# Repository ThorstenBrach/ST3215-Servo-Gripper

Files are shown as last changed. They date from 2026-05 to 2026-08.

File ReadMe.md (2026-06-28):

# ST3215 Servo Gripper














## Sprache / Language

- Deutsch: [Zur deutschen Version](#de-start)
- English: [Jump to English version](#en-start)

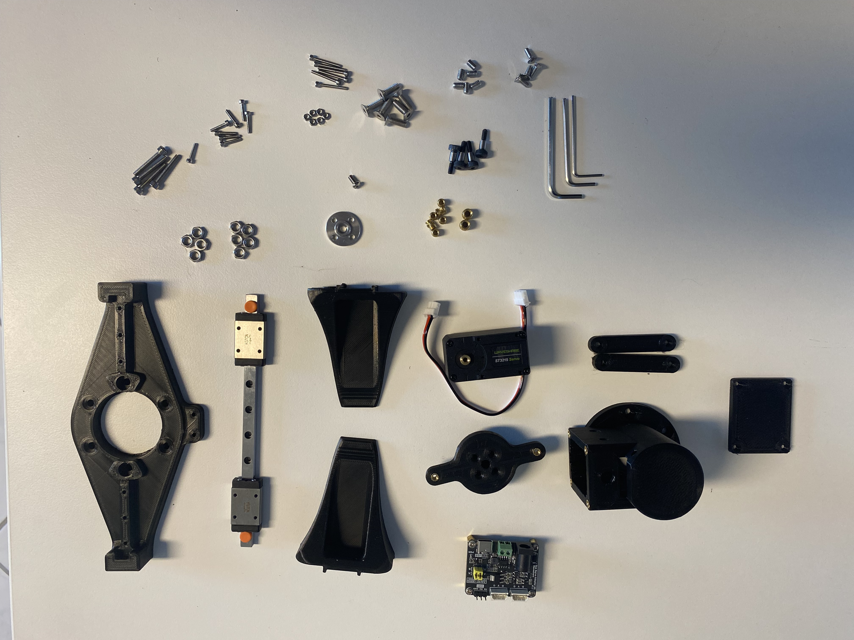
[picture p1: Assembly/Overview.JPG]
Servo Gripper Overview

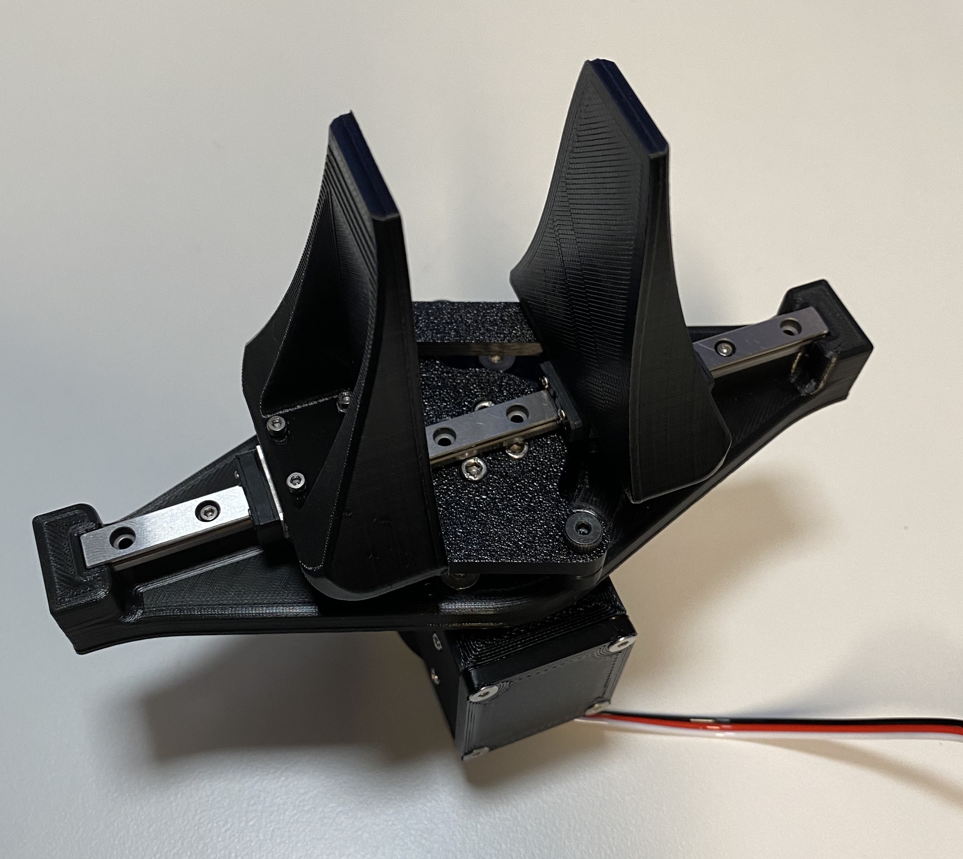
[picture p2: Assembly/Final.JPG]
Servo Gripper Final

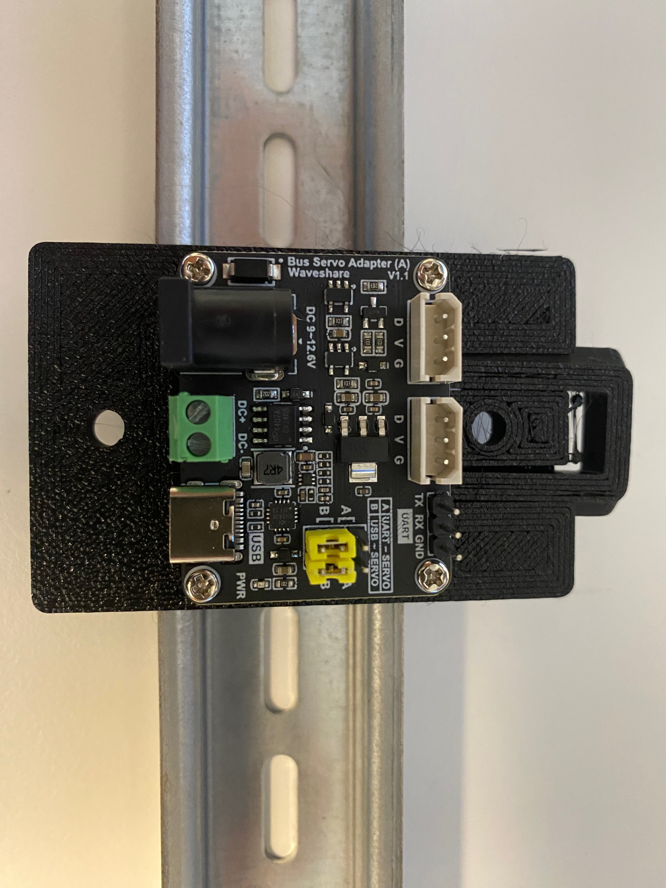
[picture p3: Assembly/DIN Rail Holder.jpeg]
DIN Rail Holder

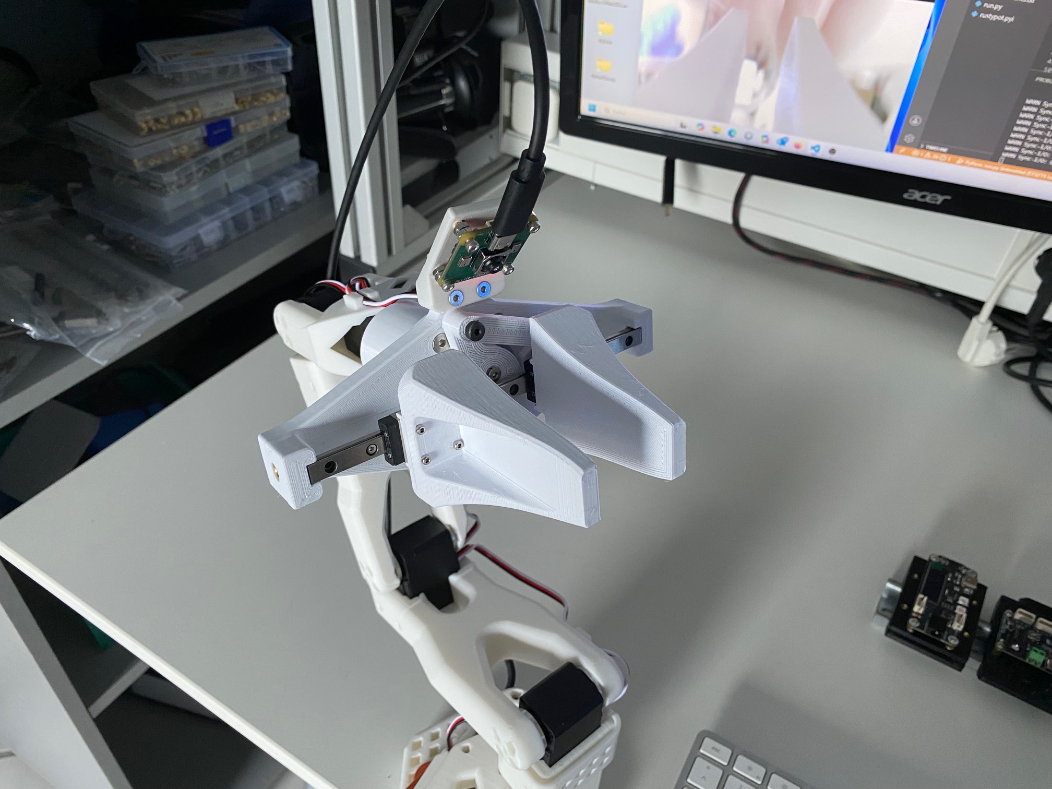
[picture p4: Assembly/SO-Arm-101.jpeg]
SO-ARM-101 Motorhousing


---

## Deutsch

[Zur Sprachauswahl](#language-selection)

Kompakter, kraftvoller ST3215 Servo Gripper zum Selberbauen mit 3D-Druckteilen, STEP-Modell, detaillierter Montageanleitung und kompletter Materialliste.

### Inhaltsverzeichnis

- [Projekt auf einen Blick](#de-ueberblick)
- [Demovideos](#de-videos)
- [Ordnerstruktur](#de-ordner)
- [Materialliste](#de-bom)
- [3D-Dateien (STL)](#de-stl)
- [CAD-Datei (STEP)](#de-step)
- [Montageanleitung](#de-assembly)
- [Software](#de-software)
- [Druck- und Setup-Hinweise](#de-hinweise)
- [Roadmap](#de-roadmap)
- [Mitwirken](#de-contrib)
- [Changelog](#de-changelog)
- [Lizenz](#de-license)

### Projekt auf einen Blick

| Thema | Details |
|---|---|
| Projekttyp | ST3215 Servo Gripper |
| Mechanik | 3D-gedruckte Baugruppen + Linearfuehrung MGN7H |
| Aktorik | Waveshare ST3215 Serial Bus Servo |
| CAD | STEP-Modell verfuegbar |
| Fertigung | STL-Dateien im Repository |
| Montage | Bebilderte Anleitung mit 25 Schritten |

### Demovideos

- Gesamtansicht: [Overview.mp4](./Video/Overview.mp4)
- Krafttest: [Force.mp4](./Video/Force.mp4)
- Anwendung mit Flasche: [Beer Bottle.mp4](./Video/Beer%20Bottle.mp4)

ST3215 Servo Gripper Overview GIF
ST3215 Servo Gripper Force Test GIF
ST3215 Servo Gripper Beer Bottle GIF

### Ordnerstruktur

| Ordner | Inhalt |
|---|---|
| [Assembly](./Assembly/) | Schritt-fuer-Schritt-Montage inkl. Bilder |
| [Material](./Material/) | Materialliste mit Mengen, Kosten und Links |
| [Software](./Software/) | Steuerungs-Software (in Entwicklung) |
| [Step](./Step/) | CAD-Datei im STEP-Format |
| [STL](./STL/) | Druckdateien fuer alle Bauteile |
| [Video](./Video/) | Demo- und Funktionstest-Videos |

### Materialliste

- [Material/Readme.md](./Material/Readme.md)

### 3D-Dateien (STL)

- [Baseplate.stl](./STL/Baseplate.stl)
- [Cam Holder.stl](./STL/Cam%20Holder.stl)
- [DIN Rail Holder Serial Board.stl](./STL/DIN%20Rail%20Holder%20Serial%20Board.stl)
- [DIN Rail Holder ESP32 Adapter.stl](./STL/DIN%20Rail%20Holder%20ESP32%20Adapter.stl)
- [Finger_1.stl](./STL/Finger_1.stl)
- [Finger_2.stl](./STL/Finger_2.stl)
- [Motorhousing.stl](./STL/Motorhousing.stl)
- [Motorhousing Cover.stl](./STL/Motorhousing%20Cover.stl)
- [Motorhousing Cover with Handle.stl](./STL/Motorhousing%20Cover%20with%20Handle.stl)
- [Motorhousing SO-ARM-101.stl](./STL/Motorhousing%20SO-ARM-101.stl)
- [Schwing Arm 1.stl](./STL/Schwing%20Arm%201.stl)
- [Schwing Arm 2.stl](./STL/Schwing%20Arm%202.stl)
- [Turnhead.stl](./STL/Turnhead.stl)

### CAD-Datei (STEP)

- [DIN Rail Holder Serial Board.step](./Step/DIN%20Rail%20Holder%20Serial%20Board.step)
- [Gripper.step](./Step/Gripper.step)

### Montageanleitung

- [Assembly/Readme.md](./Assembly/Readme.md)

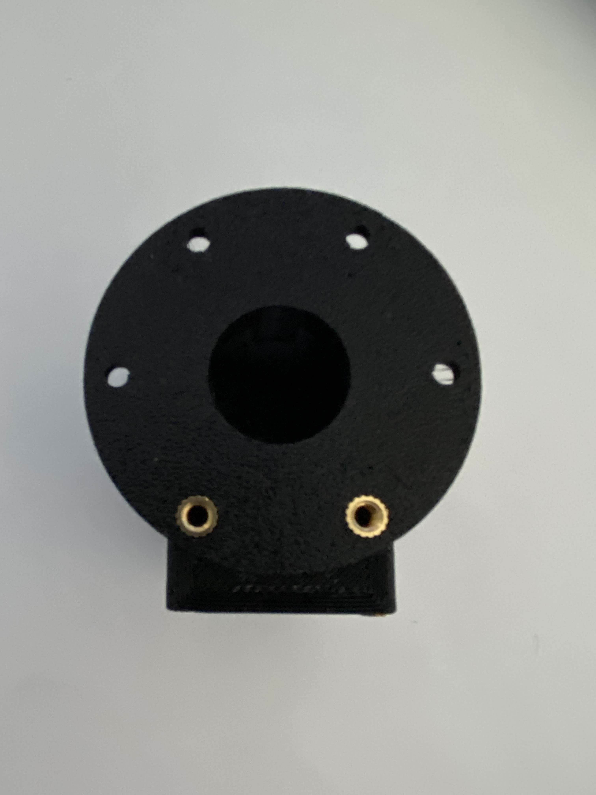
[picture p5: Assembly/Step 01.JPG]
Assembly Step 01

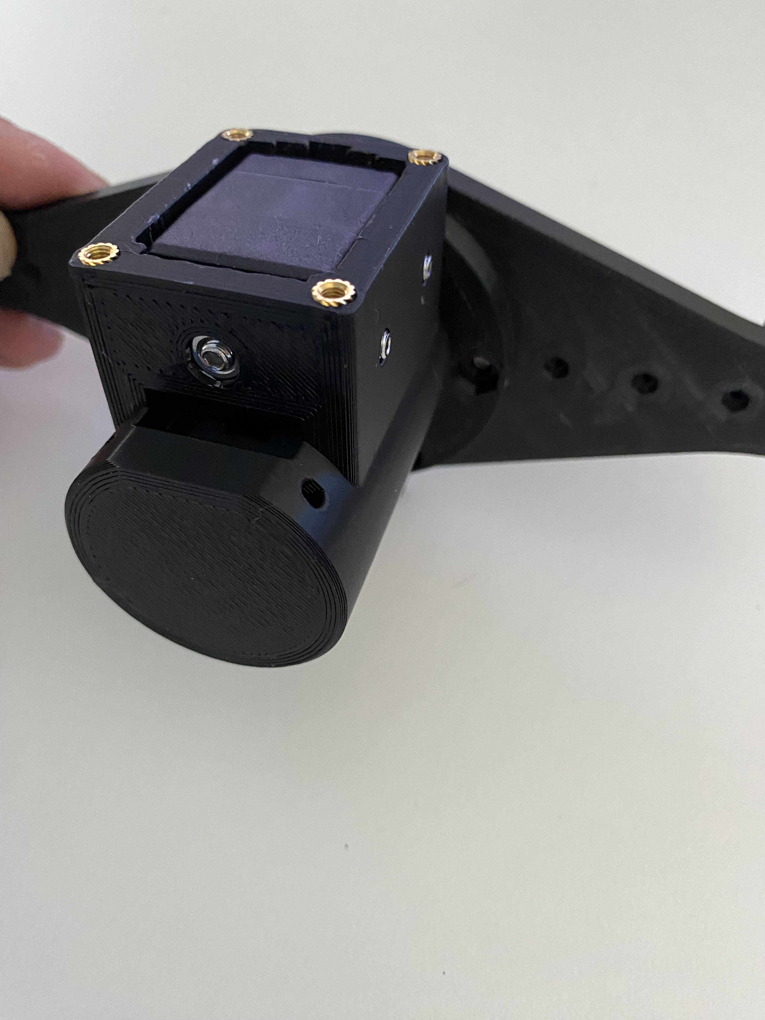
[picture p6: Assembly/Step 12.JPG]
Assembly Step 12

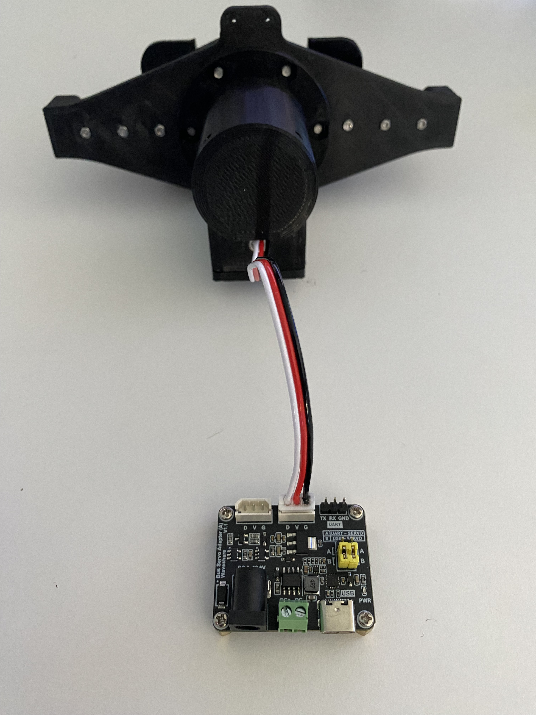
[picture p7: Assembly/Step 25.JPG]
Assembly Step 25


### Software

> **In Entwicklung** — Geplant sind Python- und IEC 61131-3-Implementierungen.
> In der Zwischenzeit kann die Software des SO-101-Projekts direkt verwendet werden — gleicher Servo, gleicher Treiber.

- [Software/Readme.md](./Software/Readme.md)

### Druck- und Setup-Hinweise

- Gewindeeinsaetze sauber und buendig einschmelzen.
- Bewegliche Baugruppen nach Montage auf Leichtgaengigkeit pruefen.
- Schraubenlaengen bei Toleranzabweichungen fein nacharbeiten.
- Erste Funktionstests ohne Last durchfuehren.

### Roadmap

- [ ] Python-Bibliothek fuer direkte Greifer-Steuerung
- [ ] IEC 61131-3 Funktionsbaustein fuer SPS-Steuerungen
- [ ] Parametrische Varianten fuer unterschiedliche Hubwege
- [ ] Standardisierte Test- und Kalibriersequenz
- [ ] Erweiterte Kompatibilitaet mit weiteren Servo-Treibern

### Mitwirken

Issues und Pull Requests sind willkommen.

### Changelog

Alle Versionen und Änderungen: [CHANGELOG.md](./CHANGELOG.md)

### Lizenz

MIT — siehe [LICENSE](./LICENSE)

[Zur Sprachauswahl](#language-selection)

Donate with PayPal (https://www.paypal.com/donate/?hosted_button_id=ERN6VH9WA95J6)

---

## English

[Back to language selection](#language-selection)

Compact, high-torque ST3215 Servo Gripper with 3D-printed parts, STEP model, detailed assembly guide, and complete bill of materials.

### Table of Contents

- [Project Overview](#en-overview)
- [Demo Videos](#en-videos)
- [Folder Structure](#en-folders)
- [Bill of Materials](#en-bom)
- [3D Files (STL)](#en-stl)
- [CAD File (STEP)](#en-step)
- [Assembly Guide](#en-assembly)
- [Software](#en-software)
- [Print and Setup Notes](#en-notes)
- [Roadmap](#en-roadmap)
- [Contributing](#en-contrib)
- [Changelog](#en-changelog)
- [License](#en-license)

### Project Overview

| Topic | Details |
|---|---|
| Project Type | ST3215 Servo Gripper |
| Mechanics | 3D-printed assemblies + MGN7H linear rail |
| Actuation | Waveshare ST3215 serial bus servo |
| CAD | STEP model available |
| Manufacturing | STL files included |
| Assembly | Illustrated guide with 25 steps |

### Demo Videos

- Full overview: [Overview.mp4](./Video/Overview.mp4)
- Force test: [Force.mp4](./Video/Force.mp4)
- Bottle handling demo: [Beer Bottle.mp4](./Video/Beer%20Bottle.mp4)

ST3215 Servo Gripper Overview GIF
ST3215 Servo Gripper Force Test GIF
ST3215 Servo Gripper Beer Bottle GIF

### Folder Structure

| Folder | Content |
|---|---|
| [Assembly](./Assembly/) | Step-by-step build guide with images |
| [Material](./Material/) | Bill of materials with quantities and links |
| [Software](./Software/) | Control software (in development) |
| [Step](./Step/) | CAD source file in STEP format |
| [STL](./STL/) | Printable files for all parts |
| [Video](./Video/) | Demo and test videos |

### Bill of Materials

- [Material/Readme.md](./Material/Readme.md)

### 3D Files (STL)

- [Baseplate.stl](./STL/Baseplate.stl)
- [Cam Holder.stl](./STL/Cam%20Holder.stl)
- [DIN Rail Holder Serial Board.stl](./STL/DIN%20Rail%20Holder%20Serial%20Board.stl)
- [DIN Rail Holder ESP32 Adapter.stl](./STL/DIN%20Rail%20Holder%20ESP32%20Adapter.stl)
- [Finger_1.stl](./STL/Finger_1.stl)
- [Finger_2.stl](./STL/Finger_2.stl)
- [Motorhousing.stl](./STL/Motorhousing.stl)
- [Motorhousing Cover.stl](./STL/Motorhousing%20Cover.stl)
- [Motorhousing Cover with Handle.stl](./STL/Motorhousing%20Cover%20with%20Handle.stl)
- [Motorhousing SO-ARM-101.stl](./STL/Motorhousing%20SO-ARM-101.stl)
- [Schwing Arm 1.stl](./STL/Schwing%20Arm%201.stl)
- [Schwing Arm 2.stl](./STL/Schwing%20Arm%202.stl)
- [Turnhead.stl](./STL/Turnhead.stl)

### CAD File (STEP)

- [DIN Rail Holder Serial Board.step](./Step/DIN%20Rail%20Holder%20Serial%20Board.step)
- [Gripper.step](./Step/Gripper.step)

### Assembly Guide

- [Assembly/Readme.md](./Assembly/Readme.md)

Assembly Step 01
Assembly Step 12
Assembly Step 25

### Software

> **Work in progress** — Python and IEC 61131-3 implementations are planned.
> Until then, the SO-101 project software works directly — same servo, same driver.

- [Software/Readme.md](./Software/Readme.md)

### Print and Setup Notes

- Install threaded inserts flush with the surface.
- Verify smooth motion of all moving parts after assembly.
- Adjust screw lengths if tolerances differ between printers.
- Run first functional tests without payload.

### Roadmap

- [ ] Python library for direct gripper control
- [ ] IEC 61131-3 function block for PLC integration
- [ ] Parametric variants for different stroke lengths
- [ ] Standardized calibration and test routine
- [ ] Extended compatibility with additional servo controllers

### Contributing

Issues and pull requests are welcome.

### Changelog

All versions and changes: [CHANGELOG.md](./CHANGELOG.md)

### License

MIT — see [LICENSE](./LICENSE)

[Back to language selection](#language-selection)

Donate with PayPal (https://www.paypal.com/donate/?hosted_button_id=ERN6VH9WA95J6)

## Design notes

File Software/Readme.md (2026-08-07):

# ST3215 Servo Gripper Software

## Sprache / Language

- Deutsch: [Zur deutschen Version](#de-start)
- English: [Jump to English version](#en-start)

---

## Deutsch

[Zur Sprachauswahl](#language-selection)

### Projektstatus

> **In Entwicklung** — Die ESP32-Firmware für den TcpIp_Server ist bereits vorhanden und dokumentiert: [ESP32/Readme.md](ESP32/Readme.md)
> Bereits vorhanden:
>
> - **Python TCP/IP Bridge** — Anbindung an das Waveshare Serial Bus Servo Driver Board über `rustypot`
>
> Weiter geplant:
>
> - **IEC 61131-3 (Structured Text)** — Einbindung in SPS-Steuerungen (PLC)

### ESP32-Firmware

Der aktuelle Stand der ESP32-Firmware liegt im Ordner [ESP32/TcpIp_Server](ESP32/TcpIp_Server) und ist in [ESP32/Readme.md](ESP32/Readme.md) beschrieben.

Die Dokumentation enthält:

- benötigte Arduino-Pakete
- verwendete Ports und Pinbelegung
- TCP-Befehle inklusive Beispielaufrufen
- kurze Hinweise zur Weboberfläche

### Python TCP/IP Bridge (Deutsch)

Zusätzlich zur ESP32-Firmware gibt es bereits ein Python-Beispiel als TCP/IP-Bridge zum Waveshare Serial Bus Servo Driver Board. Die Bridge nimmt TCP-Kommandos entgegen und steuert die Servos seriell über `rustypot`.

Enthalten sind:

- ein TCP-Command-Server
- ein einfacher Test-Client
- eine separate Setup- und Protokoll-Dokumentation unter [Python TcpIp Bridge/README.md](Python%20TcpIp%20Bridge/README.md)

---

### In der Zwischenzeit: Referenzprojekte

Der Greifer nutzt denselben Servo (Waveshare ST3215) und denselben Treiber (Waveshare Serial Bus Servo Driver) wie mehrere bekannte Open-Source-Robotikprojekte.
Die dort verwendete Software ist direkt übertragbar.

#### SO-ARM100 / SO-101 Roboterarm (HuggingFace / The Robot Studio)

Das SO-101-Projekt ist ein vollständiger 6-DOF-Roboterarm, der ebenfalls den ST3215-Servo und den Waveshare-Treiber verwendet.
Die zugehörige Python-Bibliothek `lerobot` von HuggingFace ermöglicht die direkte Servo-Steuerung.

| Thema | Details |
|---|---|
| Projekt | SO-ARM100 / SO-101 |
| Repository | [github.com/huggingface/lerobot](https://github.com/huggingface/lerobot) |
| Hardware-Guide | [github.com/TheRobotStudio/SO-ARM100](https://github.com/TheRobotStudio/SO-ARM100) |
| Sprache | Python |
| Servo-Treiber | Waveshare Serial Bus Servo Driver (identisch) |

#### Schnellstart mit lerobot (Python)

```bash
# Repository klonen
git clone https://github.com/huggingface/lerobot.git
cd lerobot

# Abhängigkeiten installieren
pip install -e ".[feetech]"
```

```python
from lerobot.common.robot_devices.motors.feetech import FeetechMotorsBus

# Verbindung zum Waveshare Treiber herstellen
# Port anpassen: Windows z.B. "COM3", Linux z.B. "/dev/ttyUSB0"
bus = FeetechMotorsBus(
    port="COM3",
    motors={
        "gripper": (1, "sts3215"),  # Motor-ID und Modell anpassen
    },
)
bus.connect()

# Position lesen
pos = bus.read("Present_Position", "gripper")
print(f"Aktuelle Position: {pos}")

# Greifer schließen (Zielposition setzen)
bus.write("Goal_Position", 2048, "gripper")
```

> Hinweis: Die Motor-ID und der COM-Port müssen auf die eigene Konfiguration angepasst werden.
> Die ID lässt sich mit dem Waveshare-Tool oder über das lerobot-Konfigurationsscript setzen.

#### Amazing Hand (Rollen Robotics) — rustypot / Rust

Die Amazing Hand von Rollen Robotics ist eine anthropomorphe Roboterhand, die dasselbe Waveshare Serial Bus Servo Driver Board einsetzt.
Als Steuerungsbibliothek wird `rustypot` verwendet — eine in Rust geschriebene Low-Level-Bibliothek für das Feetech/Dynamixel-Protokoll.
`rustypot` kommuniziert direkt über die serielle Schnittstelle und ist damit besonders geeignet für eingebettete Systeme und Echtzeit-Anwendungen.

| Thema | Details |
|---|---|
| Projekt | Amazing Hand |
| Hersteller | [Rollen Robotics](https://github.com/rollen-robotics) |
| Bibliothek | [rustypot](https://github.com/pollen-robotics/rustypot) |
| Sprache | Rust |
| Servo-Treiber | Waveshare Serial Bus Servo Driver (identisch) |

#### Schnellstart mit rustypot (Rust)

```toml
# Cargo.toml
[dependencies]
rustypot = "0.11"
```

```rust
use rustypot::device::sts3215;
use rustypot::DynamixelSerialIO;
use std::time::Duration;

fn main() {
    // Serielle Verbindung öffnen
    // Port anpassen: Windows z.B. "COM3", Linux z.B. "/dev/ttyUSB0"
    let serial_port = serialport::new("COM3", 1_000_000)
        .timeout(Duration::from_millis(10))
        .open()
        .expect("Seriellen Port konnte nicht geoeffnet werden");

    let io = DynamixelSerialIO::v1();

    // Aktuelle Position lesen (Motor-ID 1)
    let pos = sts3215::sync_read_present_position(&io, &mut *serial_port.try_clone().unwrap(), &[1])
        .expect("Lesen fehlgeschlagen");
    println!("Aktuelle Position: {:?}", pos);

    // Greifer schliessen (Zielposition setzen)
    sts3215::sync_write_goal_position(&io, &mut *serial_port.try_clone().unwrap(), &[1], &[2048])
        .expect("Schreiben fehlgeschlagen");
}
```

> Hinweis: Baudrate (1 000 000) und Motor-ID müssen auf die eigene Konfiguration abgestimmt werden.

#### Weitere Referenzen mit ST3215 / Waveshare

- [Feetech SCS/STS Protokoll-Dokumentation](https://www.feetechrc.com/STS3215.html)
- [Waveshare Serial Servo Driver Wiki](https://www.waveshare.com/wiki/Serial_Bus_Servo_Driver_HAT)

---

### Weitere geplante Implementierungen

#### IEC 61131-3 Structured Text (geplant)

- Funktionsbaustein (FB) für die serielle Servo-Kommunikation
- Kompatibel mit gängigen SPS-Systemen (Beckhoff TwinCAT, CODESYS)
- Beispielprogramm: Greifer öffnen / schließen / Kraftbegrenzung

### Lizenz

MIT — siehe [LICENSE](../LICENSE) | Änderungshistorie: [CHANGELOG.md](../CHANGELOG.md)

[Zur Sprachauswahl](#language-selection)

---

## English

[Back to language selection](#language-selection)

### Project Status

> **Work in progress** — The ESP32 firmware for the TcpIp_Server already exists and is documented here: [ESP32/Readme.md](ESP32/Readme.md)
> Already available:
>
> - **Python TCP/IP Bridge** — connection to the Waveshare Serial Bus Servo Driver board via `rustypot`
>
> Still planned:
>
> - **IEC 61131-3 (Structured Text)** — Integration into PLC controllers

### ESP32 firmware

The current ESP32 firmware lives in [ESP32/TcpIp_Server](ESP32/TcpIp_Server) and is documented in [ESP32/Readme.md](ESP32/Readme.md).

The documentation includes:

- required Arduino packages
- used ports and pin mapping
- TCP commands with example usage
- brief web UI notes

### Python TCP/IP Bridge (English)

In addition to the ESP32 firmware, there is already a Python example that acts as a TCP/IP bridge to the Waveshare Serial Bus Servo Driver board. The bridge accepts TCP commands and controls the servos over a serial connection via `rustypot`.

It includes:

- a TCP command server
- a simple test client
- separate setup and protocol documentation in [Python TcpIp Bridge/README.md](Python%20TcpIp%20Bridge/README.md)

---

### In the meantime: Reference Projects

This gripper uses the same servo (Waveshare ST3215) and the same driver (Waveshare Serial Bus Servo Driver) as several well-known open-source robotics projects.
The software from those projects is directly applicable.

#### SO-ARM100 / SO-101 Robot Arm (HuggingFace / The Robot Studio)

The SO-101 project is a complete 6-DOF robot arm that also uses the ST3215 servo and the Waveshare driver.
The accompanying Python library `lerobot` by HuggingFace enables direct servo control.

| Topic | Details |
|---|---|
| Project | SO-ARM100 / SO-101 |
| Repository | [github.com/huggingface/lerobot](https://github.com/huggingface/lerobot) |
| Hardware Guide | [github.com/TheRobotStudio/SO-ARM100](https://github.com/TheRobotStudio/SO-ARM100) |
| Language | Python |
| Servo driver | Waveshare Serial Bus Servo Driver (identical hardware) |

#### Quick Start with lerobot (Python)

```bash
# Clone repository
git clone https://github.com/huggingface/lerobot.git
cd lerobot

# Install dependencies
pip install -e ".[feetech]"
```

```python
from lerobot.common.robot_devices.motors.feetech import FeetechMotorsBus

# Connect to Waveshare driver
# Adjust port: Windows e.g. "COM3", Linux e.g. "/dev/ttyUSB0"
bus = FeetechMotorsBus(
    port="COM3",
    motors={
        "gripper": (1, "sts3215"),  # adjust motor ID and model
    },
)
bus.connect()

# Read current position
pos = bus.read("Present_Position", "gripper")
print(f"Current position: {pos}")

# Close gripper (set target position)
bus.write("Goal_Position", 2048, "gripper")
```

> Note: Motor ID and COM port must be adjusted to match your setup.
> The ID can be set using the Waveshare configuration tool or the lerobot setup script.

#### Amazing Hand (Rollen Robotics) — rustypot / Rust

The Amazing Hand by Rollen Robotics is an anthropomorphic robot hand that uses the exact same Waveshare Serial Bus Servo Driver board.
Control is handled via `rustypot` — a low-level Rust library for the Feetech/Dynamixel protocol.
`rustypot` communicates directly over serial and is therefore well suited for embedded systems and real-time applications.

| Topic | Details |
|---|---|
| Project | Amazing Hand |
| Manufacturer | [Rollen Robotics](https://github.com/rollen-robotics) |
| Library | [rustypot](https://github.com/pollen-robotics/rustypot) |
| Language | Rust |
| Servo driver | Waveshare Serial Bus Servo Driver (identical hardware) |

#### Quick Start with rustypot (Rust)

```toml
# Cargo.toml
[dependencies]
rustypot = "0.11"
```

```rust
use rustypot::device::sts3215;
use rustypot::DynamixelSerialIO;
use std::time::Duration;

fn main() {
    // Open serial connection
    // Adjust port: Windows e.g. "COM3", Linux e.g. "/dev/ttyUSB0"
    let serial_port = serialport::new("COM3", 1_000_000)
        .timeout(Duration::from_millis(10))
        .open()
        .expect("Failed to open serial port");

    let io = DynamixelSerialIO::v1();

    // Read current position (motor ID 1)
    let pos = sts3215::sync_read_present_position(&io, &mut *serial_port.try_clone().unwrap(), &[1])
        .expect("Read failed");
    println!("Current position: {:?}", pos);

    // Close gripper (set target position)
    sts3215::sync_write_goal_position(&io, &mut *serial_port.try_clone().unwrap(), &[1], &[2048])
        .expect("Write failed");
}
```

> Note: Baud rate (1 000 000) and motor ID must match your specific configuration.

#### More References for ST3215 / Waveshare

- [Feetech SCS/STS Protocol Documentation](https://www.feetechrc.com/STS3215.html)
- [Waveshare Serial Servo Driver Wiki](https://www.waveshare.com/wiki/Serial_Bus_Servo_Driver_HAT)

---

### Further Planned Implementations

#### IEC 61131-3 Structured Text (planned)

- Function block (FB) for serial servo communication
- Compatible with common PLC systems (Beckhoff TwinCAT, CODESYS)
- Example program: open / close gripper / force limiting

### License

MIT — see [LICENSE](../LICENSE) | Change history: [CHANGELOG.md](../CHANGELOG.md)

[Back to language selection](#language-selection)

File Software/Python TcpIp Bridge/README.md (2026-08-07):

# IP_ST3215_Servo_Bridge (Python)

## Language / Sprache

- [Deutsch](#deutsch)
- [English](#english)

## Deutsch

Dieses Projekt enthaelt eine Python TCP-Command-Bridge fuer die Kommunikation mit STS/SCS-Servos ueber `rustypot`.

## Projektstruktur

- `PythonExample/TcpIp_Bridge_CmdServer.py`
	- Neuer TCP-Command-Server (CRLF, Cmd-Enum, `servo_id` immer in Antwort)
- `PythonExample/TcpIp_Bridge_CmdClient.py`
	- Test-Client fuer Demo und Einzelkommandos

## Voraussetzungen

1. Python-Umgebung aktivieren
2. `rustypot` muss in der aktiven venv installiert sein
3. Richtiger COM-Port muss verfuegbar sein (z. B. `COM6`)

## Installation

Empfohlene Einrichtung im Ordner `Python TcpIp Bridge`:

```powershell
python -m venv .venv
.\.venv\Scripts\Activate.ps1
python -m pip install --upgrade pip
python -m pip install -r requirements.txt
```

`requirements.txt` installiert das lokale Paket `rustypot-1.4.2` editierbar, damit die Python-Beispiele direkt damit arbeiten koennen.

## Was ins Git-Repo gehoert

Ins Repo gehoeren der Python-Code, `requirements.txt`, README-Dateien und bei Bedarf der angepasste `rustypot-1.4.2`-Quellcode.

Nicht ins Repo gehoeren lokale und generierte Dateien wie `.venv/`, `.venv312/`, `__pycache__/`, `.mypy_cache/` und `rustypot-1.4.2/target/`.

## Start: Command Server

Empfohlener lokaler Test (localhost):

```powershell
$env:SERVO_COM_PORT='COM6'
$env:BRIDGE_HOST='127.0.0.1'
& ".\.venv312\Scripts\python.exe" ".\PythonExample\TcpIp_Bridge_CmdServer.py"
```

Optionaler Netzwerkbetrieb:

```powershell
$env:SERVO_COM_PORT='COM6'
$env:BRIDGE_HOST='0.0.0.0'
$env:BRIDGE_PORT='54600'
& ".\.venv312\Scripts\python.exe" ".\PythonExample\TcpIp_Bridge_CmdServer.py"
```

## Start: Command Client

Hilfe anzeigen:

```powershell
& ".\.venv312\Scripts\python.exe" ".\PythonExample\TcpIp_Bridge_CmdClient.py" --help
```

Demo-Sequenz (Cmd 1..5):

```powershell
& ".\.venv312\Scripts\python.exe" ".\PythonExample\TcpIp_Bridge_CmdClient.py" --host 127.0.0.1 demo --servo-id 1 --position 0.2 --speed 6
```

Einzelkommando senden:

```powershell
& ".\.venv312\Scripts\python.exe" ".\PythonExample\TcpIp_Bridge_CmdClient.py" --host 127.0.0.1 send --cmd 4 --param servo_id=1
```

## Protokoll: Request/Response

Transport:

- TCP
- Eine Nachricht pro Zeile
- Zeilenende: `CRLF` (`\r\n`)

Request-Format:

```text
Cmd=<id>;param1=value1;param2=value2\r\n
```

Success-Response:

```text
Cmd=<id>;servo_id=<id_oder_csv>;result=OK;...\r\n
```

Error-Response:

```text
Cmd=<id>;servo_id=<id_oder_csv_oder_UNKNOWN>;result=ERR;error_code=<n>;message=<text>\r\n
```

Wichtig:

- `servo_id` ist immer in jeder Antwort enthalten (auch bei Fehlern)

## Cmd-Enum

Die aktuelle Command-Menge basiert auf dem lokalen Stub von `Scs0009PyController`:

1. `Cmd=1` -> `write_torque_enable(servo_id, mode)`
2. `Cmd=2` -> `write_goal_speed(servo_id, speed)`
3. `Cmd=3` -> `write_goal_position(servo_id, position)`
4. `Cmd=4` -> `read_present_position(servo_id)`
5. `Cmd=5` -> `sync_write_raw_goal_position(ids, positions)`

## Beispiel-Strings (direkt nutzbar)

### Cmd 1: Torque Enable

Request:

```text
Cmd=1;servo_id=1;mode=1\r\n
```

Response (OK):

```text
Cmd=1;servo_id=1;result=OK\r\n
```

### Cmd 2: Goal Speed

Request:

```text
Cmd=2;servo_id=1;speed=6\r\n
```

Response (OK):

```text
Cmd=2;servo_id=1;result=OK\r\n
```

### Cmd 3: Goal Position (radians)

Request:

```text
Cmd=3;servo_id=1;position=0.2\r\n
```

Response (OK):

```text
Cmd=3;servo_id=1;result=OK\r\n
```

### Cmd 4: Read Present Position

Request:

```text
Cmd=4;servo_id=1\r\n
```

Response (OK):

```text
Cmd=4;servo_id=1;result=OK;position=[0.07669903939428206]\r\n
```

### Cmd 5: Sync Write Raw Goal Position

Request:

```text
Cmd=5;ids=1,2;positions=512,600\r\n
```

Response (OK):

```text
Cmd=5;servo_id=1,2;result=OK;count=2\r\n
```

### Fehlerbeispiele

Unbekanntes Kommando:

```text
Cmd=99;servo_id=UNKNOWN;result=ERR;error_code=1001;message=unknown_command\r\n
```

Fehlender Parameter:

```text
Cmd=3;servo_id=UNKNOWN;result=ERR;error_code=1002;message=missing_servo_id\r\n
```

Ungueltiger Typ:

```text
Cmd=3;servo_id=UNKNOWN;result=ERR;error_code=1003;message=invalid_int_servo_id\r\n
```

Listenlaenge passt nicht:

```text
Cmd=5;servo_id=1,2;result=ERR;error_code=1004;message=ids_positions_length_mismatch\r\n
```

## Konfiguration per Environment Variables

- `SERVO_COM_PORT` (Default: `COM6`)
- `SERVO_BAUDRATE` (Default: `1000000`)
- `SERVO_TIMEOUT` (Default: `0.5`)
- `BRIDGE_HOST` (Default: `192.168.2.150`)
- `BRIDGE_PORT` (Default: `54600`)

## Troubleshooting

1. `WinError 10049` beim Start:
	 - `BRIDGE_HOST` ist auf dieser Maschine nicht gueltig.
	 - Fuer lokal testen: `127.0.0.1`
	 - Fuer Netzbetrieb: echte lokale Adapter-IP oder `0.0.0.0`

2. `ModuleNotFoundError: rustypot`:
	 - In der aktiven venv `rustypot` installieren

3. COM-Port Fehler (`Semaphore timeout`, `Datei nicht gefunden`):
	 - Richtigen COM-Port pruefen
	 - Port darf nicht von anderem Tool blockiert sein
	 - Kabel/USB-Adapter/Servo-Stromversorgung pruefen

## English

This project provides a Python TCP command bridge for STS/SCS servos using `rustypot`.

## Project structure

- `PythonExample/TcpIp_Bridge_CmdServer.py`
	- TCP command server (CRLF, command enum, `servo_id` always included in responses)
- `PythonExample/TcpIp_Bridge_CmdClient.py`
	- Test client for demo and single-command calls

## Requirements

1. Activate your Python environment
2. `rustypot` must be installed in the active venv
3. A valid COM port must be available (for example `COM6`)

## Installation

Recommended setup inside the `Python TcpIp Bridge` folder:

```powershell
python -m venv .venv
.\.venv\Scripts\Activate.ps1
python -m pip install --upgrade pip
python -m pip install -r requirements.txt
```

The `requirements.txt` installs the local `rustypot-1.4.2` package in editable mode so the Python examples can use it directly.

## What belongs in Git

Commit the Python source, `requirements.txt`, README files, and the `rustypot-1.4.2` source only if you actually want to vendor or modify it in this repository.

Do not commit local or generated files such as `.venv/`, `.venv312/`, `__pycache__/`, `.mypy_cache/`, or `rustypot-1.4.2/target/`.

## Start: Command Server

Recommended local test (localhost):

```powershell
$env:SERVO_COM_PORT='COM6'
$env:BRIDGE_HOST='127.0.0.1'
& ".\.venv312\Scripts\python.exe" ".\PythonExample\TcpIp_Bridge_CmdServer.py"
```

Optional network mode:

```powershell
$env:SERVO_COM_PORT='COM6'
$env:BRIDGE_HOST='0.0.0.0'
$env:BRIDGE_PORT='54600'
& ".\.venv312\Scripts\python.exe" ".\PythonExample\TcpIp_Bridge_CmdServer.py"
```

## Start: Command Client

Show help:

```powershell
& ".\.venv312\Scripts\python.exe" ".\PythonExample\TcpIp_Bridge_CmdClient.py" --help
```

Run demo sequence (Cmd 1..5):

```powershell
& ".\.venv312\Scripts\python.exe" ".\PythonExample\TcpIp_Bridge_CmdClient.py" --host 127.0.0.1 demo --servo-id 1 --position 0.2 --speed 6
```

Send a single command:

```powershell
& ".\.venv312\Scripts\python.exe" ".\PythonExample\TcpIp_Bridge_CmdClient.py" --host 127.0.0.1 send --cmd 4 --param servo_id=1
```

## Protocol: Request/Response

Transport:

- TCP
- One message per line
- Line ending: `CRLF` (`\r\n`)

Request format:

```text
Cmd=<id>;param1=value1;param2=value2\r\n
```

Success response:

```text
Cmd=<id>;servo_id=<id_or_csv>;result=OK;...\r\n
```

Error response:

```text
Cmd=<id>;servo_id=<id_or_csv_or_UNKNOWN>;result=ERR;error_code=<n>;message=<text>\r\n
```

Important:

- `servo_id` is always present in every response (including errors)

## Command enum

The current command set is based on the local `Scs0009PyController` stub:

1. `Cmd=1` -> `write_torque_enable(servo_id, mode)`
2. `Cmd=2` -> `write_goal_speed(servo_id, speed)`
3. `Cmd=3` -> `write_goal_position(servo_id, position)`
4. `Cmd=4` -> `read_present_position(servo_id)`
5. `Cmd=5` -> `sync_write_raw_goal_position(ids, positions)`

## Example strings

### Cmd 1: Torque Enable

Request:

```text
Cmd=1;servo_id=1;mode=1\r\n
```

Response (OK):

```text
Cmd=1;servo_id=1;result=OK\r\n
```

### Cmd 2: Goal Speed

Request:

```text
Cmd=2;servo_id=1;speed=6\r\n
```

Response (OK):

```text
Cmd=2;servo_id=1;result=OK\r\n
```

### Cmd 3: Goal Position (radians)

Request:

```text
Cmd=3;servo_id=1;position=0.2\r\n
```

Response (OK):

```text
Cmd=3;servo_id=1;result=OK\r\n
```

### Cmd 4: Read Present Position

Request:

```text
Cmd=4;servo_id=1\r\n
```

Response (OK):

```text
Cmd=4;servo_id=1;result=OK;position=[0.07669903939428206]\r\n
```

### Cmd 5: Sync Write Raw Goal Position

Request:

```text
Cmd=5;ids=1,2;positions=512,600\r\n
```

Response (OK):

```text
Cmd=5;servo_id=1,2;result=OK;count=2\r\n
```

### Error examples

Unknown command:

```text
Cmd=99;servo_id=UNKNOWN;result=ERR;error_code=1001;message=unknown_command\r\n
```

Missing parameter:

```text
Cmd=3;servo_id=UNKNOWN;result=ERR;error_code=1002;message=missing_servo_id\r\n
```

Invalid type:

```text
Cmd=3;servo_id=UNKNOWN;result=ERR;error_code=1003;message=invalid_int_servo_id\r\n
```

List length mismatch:

```text
Cmd=5;servo_id=1,2;result=ERR;error_code=1004;message=ids_positions_length_mismatch\r\n
```

## Configuration via environment variables

- `SERVO_COM_PORT` (default: `COM6`)
- `SERVO_BAUDRATE` (default: `1000000`)
- `SERVO_TIMEOUT` (default: `0.5`)
- `BRIDGE_HOST` (default: `192.168.2.150`)
- `BRIDGE_PORT` (default: `54600`)

## Troubleshooting

1. `WinError 10049` at startup:
	 - `BRIDGE_HOST` is invalid on this machine.
	 - For local tests use: `127.0.0.1`
	 - For network mode use: a real local adapter IP or `0.0.0.0`

2. `ModuleNotFoundError: rustypot`:
	 - Install `rustypot` in the active venv

3. COM port issues (`Semaphore timeout`, `File not found`):
	 - Verify correct COM port
	 - Ensure port is not locked by another tool
	 - Check cable/USB adapter/servo power

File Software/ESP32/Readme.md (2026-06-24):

# ESP32 TcpIp_Server

## Sprache / Language

- Deutsch: [Zur deutschen Version](#de-start)
- English: [Jump to English version](#en-start)

---

## Deutsch

[Zur Sprachauswahl](#language-selection)

### Überblick

Der Ordner `TcpIp_Server` enthält die ESP32-Firmware für den Servo-Treiber. Die Firmware bietet:

- WLAN im AP- oder STA-Modus
- Weboberfläche auf Port 80
- TCP-Textserver auf Port 5000
- Servo-Kommunikation über `Serial1` mit 1 000 000 Baud
- OLED-Statusanzeige und RGB-Status-LEDs

### Benötigte Versionen

Diese Kombination ist in diesem Projekt funktionierend getestet und sollte exakt so installiert werden:

| Paket | Version |
|---|---|
| `esp32` von Espressif Systems | `3.3.10` |
| `Adafruit BusIO` | `1.17.4` |
| `Adafruit GFX Library` | `1.12.6` |
| `Adafruit NeoPixel` | `1.15.5` |
| `Adafruit SSD1306` | `2.5.17` |
| `SCServo` | `1.0.2` |

Hinweise:

- `WiFi`, `WebServer`, `esp_now`, `Wire` und `Preferences` sind Teil des ESP32-Core-Pakets.
- Das Paket `Arduino ESP32 Boards` von Arduino ist für dieses Projekt nicht erforderlich, da die Firmware auf dem ESP32-Core von Espressif Systems basiert.
- Bitte keine neueren oder abweichenden Versionen der genannten Pakete verwenden, wenn die stabile Kombination aus diesem Projekt reproduziert werden soll.

### Arduino-Einstellungen

- Board: ein ESP32-Board mit WLAN-Unterstützung, für WaveShare ESP32 muss das `ESP32 Dev Module` ausgewählt sein.
- Upload über den COM-Port des angeschlossenen ESP32-Boards ( COM Port kann im Windows Gerätemanager ermittelt werden )

### Netzwerk-Ports

- HTTP/Weboberfläche: Port `80`
- TCP-Textserver: Port `5000`

Im AP-Modus ist der Standard-Access-Point:

- SSID: `ESP32_DEV`
- Passwort: `12345678`

Im STA-Modus verbindet sich der ESP32 mit dem in `PreferencesConfig.h` eingetragenen WLAN.

### TCP/IP-Server: Befehle

Der TCP-Server erwartet zeilenbasierte Texteingaben. Jede Zeile muss mit einem Zeilenumbruch abgeschlossen werden.

| Befehl | Wirkung | Beispiel |
|---|---|---|
| `PING` | Verbindungstest | `PING` |
| `GET STS` | Status des aktuell aktiven Servos | `GET STS` |
| `SEARCH` | Servos scannen | `SEARCH` |
| `CMD <nummer>` | interne Steuerfunktion ausführen | `CMD 1` |
| `SET POS <id> <pos> <speed>` | Servo direkt anfahren | `SET POS 1 511 300` |

Rückmeldungen:

- `PONG`
- `OK SEARCH`
- `OK CMD`
- `OK SET POS`
- `ERR unknown command`
- `ERR timeout`

### CMD-Befehle

`CMD` verwendet dieselben internen Aktionen wie die Weboberfläche. Die wichtigsten Zuordnungen sind:

| CMD | Aktion |
|---|---|
| `1` | Aktiven Servo auf Mittelstellung fahren |
| `2` | Stop / Hold |
| `3` | Torque aus |
| `4` | Torque an |
| `5` | Position + / öffnen |
| `6` | Position - / schließen |
| `7` | Geschwindigkeit erhöhen |
| `8` | Geschwindigkeit verringern |
| `9` | Ziel-ID erhöhen |
| `10` | Ziel-ID verringern |
| `11` | Mittelstellung kalibrieren |
| `12` | Servo-Modus setzen |
| `13` | Motor-Modus setzen |
| `14` | Serial Forwarding starten |
| `15` | Serial Forwarding stoppen |
| `16` | Neue ID schreiben |
| `17` | Normaler Modus |
| `18` | Leader-Modus |
| `19` | Follower-Modus |
| `20` | Rainbow ein |
| `21` | Rainbow aus |

### Beispiel: TCP-Server mit Python testen

```python
import socket

HOST = "192.168.4.1"  # im AP-Modus der Default-Wert
PORT = 5000

with socket.create_connection((HOST, PORT), timeout=5) as sock:
    def send(cmd: str) -> None:
        sock.sendall((cmd + "\n").encode("utf-8"))
        print(sock.recv(1024).decode("utf-8", errors="replace").strip())

    send("PING")
    send("GET STS")
    send("SEARCH")
    send("CMD 1")
    send("SET POS 1 511 300")
```

### Beispiel: Nutzung über die Weboberfläche

1. ESP32 einschalten und über Serial Monitor oder OLED die IP-Adresse ablesen.
2. Im Browser `http://<IP-Adresse>/` öffnen.
3. Über die Buttons Servos suchen, auswählen und bewegen.
4. Für direkte Statusabfragen werden die Endpunkte `readID` und `readSTS` verwendet.

### Praktische Hinweise

- Der TCP-Server arbeitet mit einer einzelnen Verbindung und trennt sie nach 30 Sekunden Inaktivität.
- Die Firmware gibt die aktuelle IP-Adresse im Serial Monitor und auf dem OLED aus.
- Die Weboberfläche und der TCP-Server laufen parallel.

---

## English

[Back to language selection](#language-selection)

### Overview

The `TcpIp_Server` folder contains the ESP32 firmware for the servo driver. It provides:

- Wi-Fi in AP or STA mode
- Web UI on port 80
- TCP text server on port 5000
- Servo communication over `Serial1` at 1,000,000 baud
- OLED status output and RGB status LEDs

### Required Versions

This project was tested and works with the exact package combination below:

| Package | Version |
|---|---|
| `esp32` by Espressif Systems | `3.3.10` |
| `Adafruit BusIO` | `1.17.4` |
| `Adafruit GFX Library` | `1.12.6` |
| `Adafruit NeoPixel` | `1.15.5` |
| `Adafruit SSD1306` | `2.5.17` |
| `SCServo` | `1.0.2` |

Notes:

- `WiFi`, `WebServer`, `esp_now`, `Wire`, and `Preferences` are part of the ESP32 core package.
- The `Arduino ESP32 Boards` package by Arduino is not required for this project because the firmware targets the Espressif Systems ESP32 core.
- Do not mix in newer or different versions of these packages if you want to reproduce the working setup from this project.

### Arduino settings

- Board: an ESP32 board with Wi-Fi support, for WaveShare ESP32 the `ESP32 Dev Module` must be selected
- Upload via the COM port of the connected ESP32 board 
  (COM Port can be detected via the Windows device manager)

### Network ports

- HTTP web UI: port `80`
- TCP text server: port `5000`

In AP mode, the default access point is:

- SSID: `ESP32_DEV`
- Password: `12345678`

### TCP/IP server commands

The TCP server uses line-based text commands. End each command with a newline.

| Command | Effect | Example |
|---|---|---|
| `PING` | connection test | `PING` |
| `GET STS` | status of the active servo | `GET STS` |
| `SEARCH` | scan for servos | `SEARCH` |
| `CMD <number>` | run an internal control action | `CMD 1` |
| `SET POS <id> <pos> <speed>` | move a servo directly | `SET POS 1 511 300` |

Typical replies:

- `PONG`
- `OK SEARCH`
- `OK CMD`
- `OK SET POS`
- `ERR unknown command`
- `ERR timeout`

### CMD mapping

`CMD` uses the same internal actions as the web UI.

| CMD | Action |
|---|---|
| `1` | Move active servo to center |
| `2` | Stop / hold |
| `3` | Torque off |
| `4` | Torque on |
| `5` | Position + / open |
| `6` | Position - / close |
| `7` | Increase speed |
| `8` | Decrease speed |
| `9` | Increase target ID |
| `10` | Decrease target ID |
| `11` | Calibrate center |
| `12` | Set servo mode |
| `13` | Set motor mode |
| `14` | Start serial forwarding |
| `15` | Stop serial forwarding |
| `16` | Write new ID |
| `17` | Normal mode |
| `18` | Leader mode |
| `19` | Follower mode |
| `20` | Rainbow on |
| `21` | Rainbow off |

### Python example

```python
import socket

HOST = "192.168.4.1"  # default in AP mode
PORT = 5000

with socket.create_connection((HOST, PORT), timeout=5) as sock:
    def send(cmd: str) -> None:
        sock.sendall((cmd + "\n").encode("utf-8"))
        print(sock.recv(1024).decode("utf-8", errors="replace").strip())

    send("PING")
    send("GET STS")
    send("SEARCH")
    send("CMD 1")
    send("SET POS 1 511 300")
```

### Web UI usage

1. Power on the ESP32 and read the IP address from the Serial Monitor or OLED.
2. Open `http://<IP address>/` in a browser.
3. Use the buttons to search, select, and move servos.
4. The `readID` and `readSTS` endpoints provide live information.

### Practical notes

- The TCP server uses a single client connection and disconnects after 30 seconds of inactivity.
- The firmware prints the current IP address to the Serial Monitor and OLED.
- The web UI and TCP server run in parallel.

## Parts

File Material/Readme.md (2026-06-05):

# ST3215 Servo Gripper Bill of Materials

## Sprache / Language

- Deutsch: [Zur deutschen BOM](#de-start)
- English: [Jump to English BOM](#en-start)

---

## Deutsch

[Zur Sprachauswahl](#language-selection)

Komplette Teileliste fuer den ST3215 Servo Gripper inkl. Mengen, Richtpreisen und Bezugsquellen.

### Mechanik und Elektronik

| Menge | Bauteil | Richtpreis | Bezugsquelle |
|---|---|---:|---|
| 1x | Linearfuehrung MGN7H 150 mm (mit 2 Wagen) | ca. 13,00 EUR | [Link](https://amzn.eu/d/0199oyQW) |
| 1x | Waveshare ST3215 Servo Motor | ca. 35,00 EUR | [Link](https://amzn.eu/d/0eCBvW0E) |
| 1x | Waveshare Serial Bus Servo Driver USB/UART | ca. 12,00 EUR | [Link](https://amzn.eu/d/0dreJulz) |
| 1x (Alternative) | Waveshare Serial Bus Servo Driver WiFi/Bluetooth | ca. 25,00 EUR | [Link](https://amzn.eu/d/0eNgh0P6) |

Hinweis: Bei der Linearfuehrung die richtige Variante (MGN7H, 150 mm, 2 Wagen) auswaehlen.

### Befestigungsmaterial M2

| Menge | Bauteil | Richtpreis | Bezugsquelle |
|---|---|---:|---|
| 8x | M2 x 8 mm Zylinderkopfschrauben | ca. 1,00 EUR | [Link](https://amzn.eu/d/0ecv99RW) |
| 6x | M2 x 20 mm Linsenkopfschrauben (Flat Head) | ca. 1,00 EUR | [Link](https://amzn.eu/d/00VYDWv8) |
| 6x | M2 Muttern | ca. 1,00 EUR | [Link](https://amzn.eu/d/0hZBuBmF) |

### Befestigungsmaterial M3

| Menge | Bauteil | Richtpreis | Bezugsquelle |
|---|---|---:|---|
| 4x | M3 x 25 mm Senkkopfschrauben | ca. 1,00 EUR | [Link](https://amzn.eu/d/0dTfInOU) |
| 4x | M3 Gewindeeinsaetze (Einschmelzmutter) | ca. 1,00 EUR | [Link](https://amzn.eu/d/07s2j5aE) |
| 4x | M3 Passschrauben M3x10 (D1=4 mm, L1=6 mm, L2=4 mm) | ca. 12,50 EUR | [Link](https://www.normteile-leinigen.de/Passschrauben-OE-4-mm-M3-x-6-mm-aus-Stahl-ISO-7379/K0705.04X06#review) |

### Befestigungsmaterial M4

| Menge | Bauteil | Richtpreis | Bezugsquelle |
|---|---|---:|---|
| 5x | M4 x 6 mm Madenschrauben | ca. 1,00 EUR | [Link](https://amzn.eu/d/0i7jxMsC) |
| 6x | M4 x 16 mm Senkkopfschrauben | ca. 1,00 EUR | [Link](https://amzn.eu/d/064vVVUk) |
| 4x | M4 Muttern | ca. 1,00 EUR | [Link](https://amzn.eu/d/0hZBuBmF) |
| 2x | M4 Gewindeeinsaetze (Einschmelzmutter) | ca. 1,00 EUR | [Link](https://amzn.eu/d/07s2j5aE) |

### Kostenuebersicht (grob)

Je nach Bezugsquelle und Lieferland liegt das Projekt typischerweise bei etwa 65 bis 90 EUR.

Hinweise:

- Preise sind Richtwerte und koennen schwanken.
- Versandkosten sind nicht beruecksichtigt.
- Optionales Werkzeug ist nicht in der BOM enthalten.

### Lizenz

MIT — siehe [LICENSE](../LICENSE) | Änderungshistorie: [CHANGELOG.md](../CHANGELOG.md)

[Zur Sprachauswahl](#language-selection)

Donate with PayPal (https://www.paypal.com/donate/?hosted_button_id=ERN6VH9WA95J6)

---

## English

[Back to language selection](#language-selection)

Complete bill of materials for the ST3215 Servo Gripper including quantities, estimated prices, and supplier links.

### Mechanics and Electronics

| Qty | Part | Estimated Price | Source |
|---|---|---:|---|
| 1x | MGN7H linear rail, 150 mm (with 2 carriages) | approx. 13.00 EUR | [Link](https://amzn.eu/d/0199oyQW) |
| 1x | Waveshare ST3215 servo motor | approx. 35.00 EUR | [Link](https://amzn.eu/d/0eCBvW0E) |
| 1x | Waveshare serial bus servo driver USB/UART | approx. 12.00 EUR | [Link](https://amzn.eu/d/0dreJulz) |
| 1x (Alternative) | Waveshare serial bus servo driver WiFi/Bluetooth | approx. 25.00 EUR | [Link](https://amzn.eu/d/0eNgh0P6) |

Note: Make sure to select the correct rail option (MGN7H, 150 mm, 2 carriages).

### M2 Hardware

| Qty | Part | Estimated Price | Source |
|---|---|---:|---|
| 8x | M2 x 8 mm socket head screws | approx. 1.00 EUR | [Link](https://amzn.eu/d/0ecv99RW) |
| 6x | M2 x 20 mm pan head screws (flat head) | approx. 1.00 EUR | [Link](https://amzn.eu/d/00VYDWv8) |
| 6x | M2 nuts | approx. 1.00 EUR | [Link](https://amzn.eu/d/0hZBuBmF) |

### M3 Hardware

| Qty | Part | Estimated Price | Source |
|---|---|---:|---|
| 4x | M3 x 25 mm countersunk screws | approx. 1.00 EUR | [Link](https://amzn.eu/d/0dTfInOU) |
| 4x | M3 threaded inserts (heat-set inserts) | approx. 1.00 EUR | [Link](https://amzn.eu/d/07s2j5aE) |
| 4x | M3 shoulder screws M3x10 (D1=4 mm, L1=6 mm, L2=4 mm) | approx. 12.50 EUR | [Link](https://www.normteile-leinigen.de/Passschrauben-OE-4-mm-M3-x-6-mm-aus-Stahl-ISO-7379/K0705.04X06#review) |

### M4 Hardware

| Qty | Part | Estimated Price | Source |
|---|---|---:|---|
| 5x | M4 x 6 mm set screws | approx. 1.00 EUR | [Link](https://amzn.eu/d/0i7jxMsC) |
| 6x | M4 x 12 mm countersunk screws | approx. 1.00 EUR | [Link](https://amzn.eu/d/064vVVUk) |
| 4x | M4 nuts | approx. 1.00 EUR | [Link](https://amzn.eu/d/0hZBuBmF) |
| 2x | M4 threaded inserts (heat-set inserts) | approx. 1.00 EUR | [Link](https://amzn.eu/d/07s2j5aE) |

### Cost Overview (rough estimate)

Depending on suppliers and shipping region, the project typically lands around 65 to 90 EUR.

Notes:

- Prices are rough estimates and may vary.
- Shipping is not included.
- Optional tools are not part of this BOM.

### License

MIT — see [LICENSE](../LICENSE) | Change history: [CHANGELOG.md](../CHANGELOG.md)

[Back to language selection](#language-selection)

Donate with PayPal (https://www.paypal.com/donate/?hosted_button_id=ERN6VH9WA95J6)

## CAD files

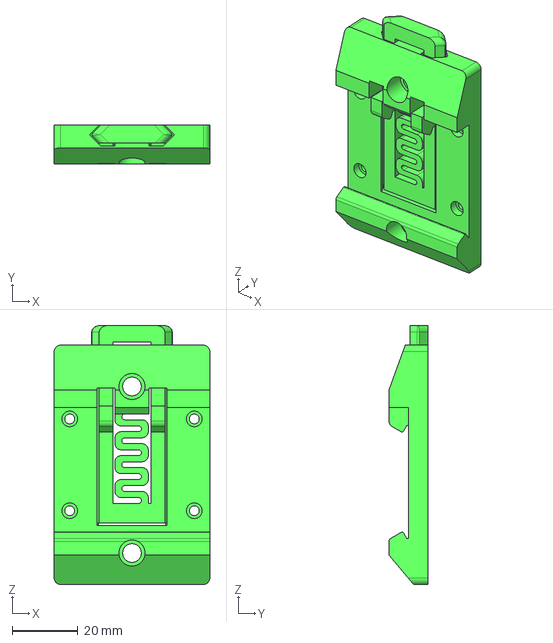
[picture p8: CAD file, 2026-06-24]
Step/DIN Rail Holder Serial Board.step
47.5 x 12.0 x 79.0 mm

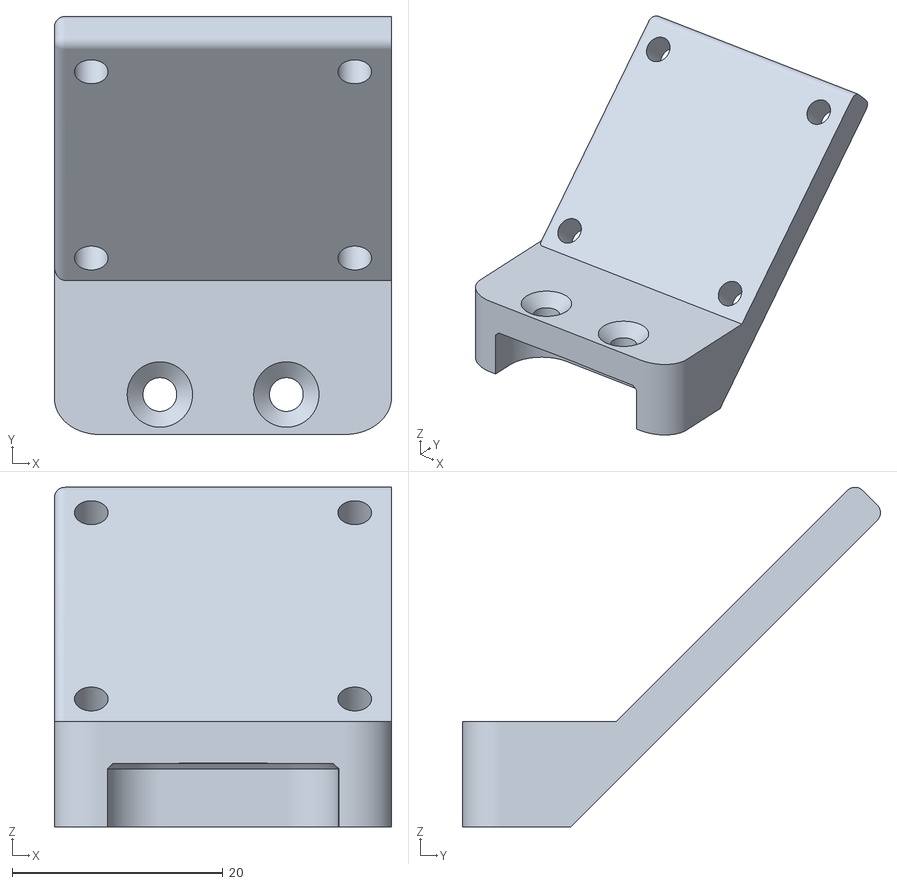
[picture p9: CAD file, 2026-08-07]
STL/Cam Holder.stl
32.0 x 39.7 x 32.2

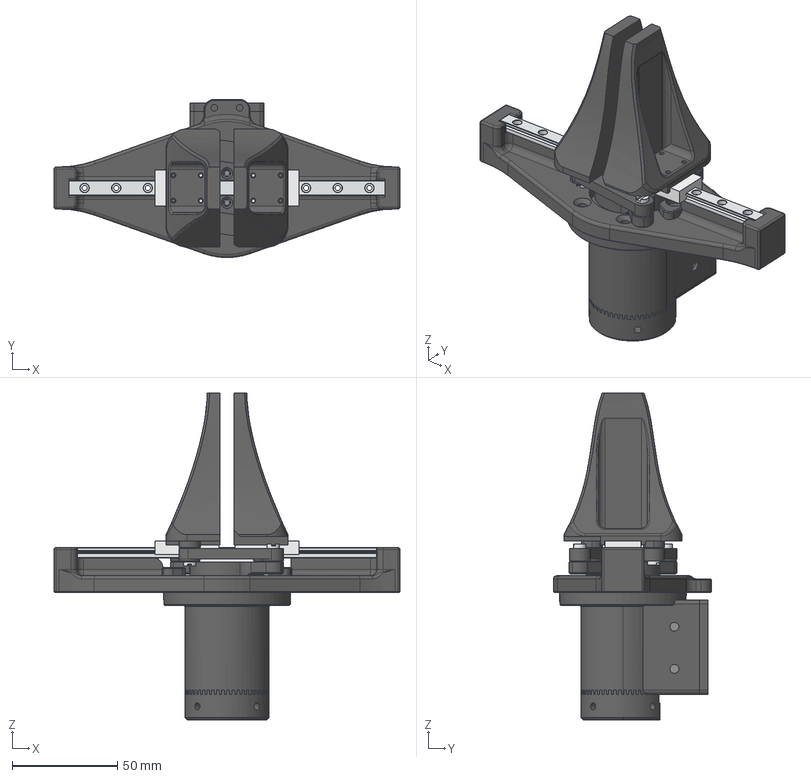
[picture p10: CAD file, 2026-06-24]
Step/Gripper.step
164.0 x 75.0 x 154.8 mm
Carrier 1
Carrier 2
Finger 1
Finger 2
Servo horn2
waveshare servo motor 30kg
Motorhousing
Baseplate
Motor Drehkranz

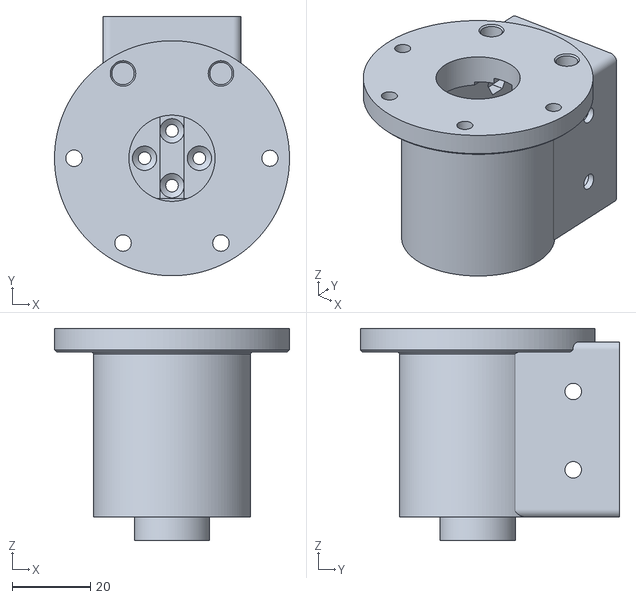
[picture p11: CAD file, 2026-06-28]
STL/Motorhousing SO-ARM-101.stl
60.0 x 66.2 x 54.2

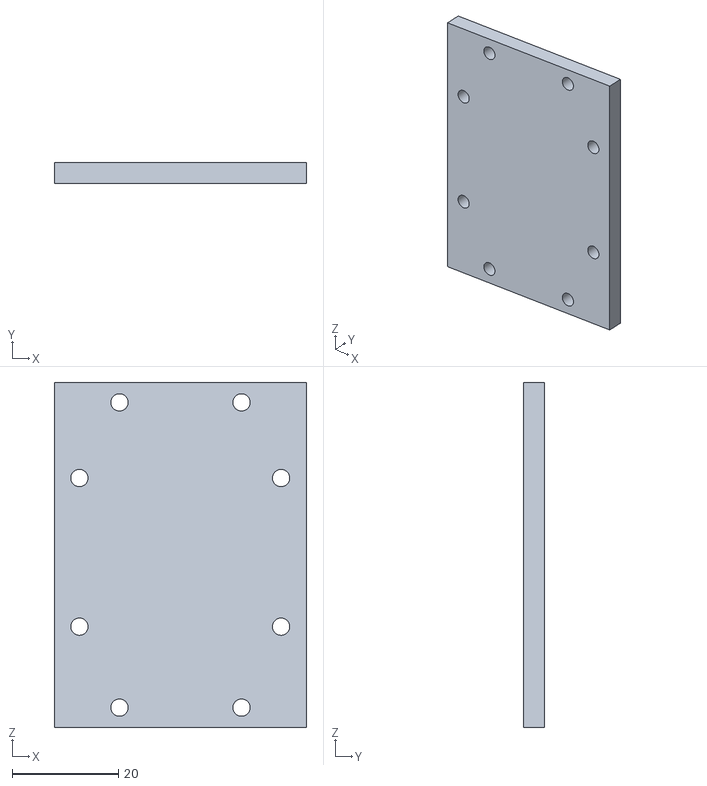
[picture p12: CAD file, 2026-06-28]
STL/DIN Rail Holder ESP32 Adapter.stl
47.5 x 4.00 x 65.0

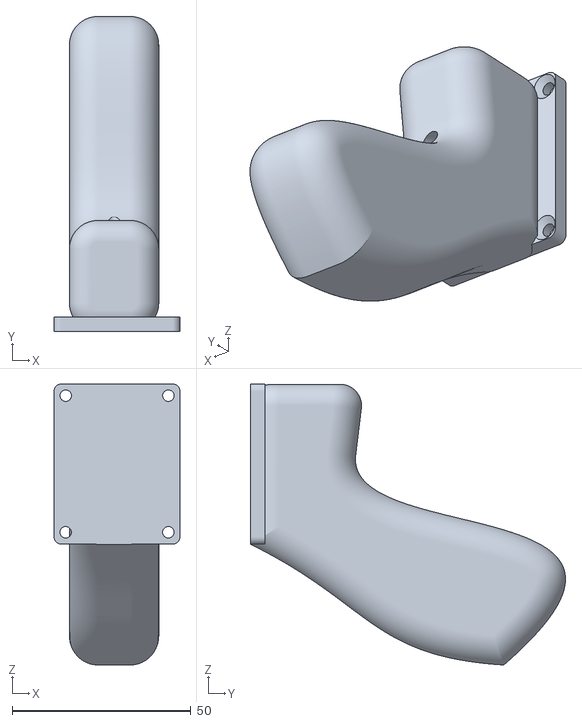
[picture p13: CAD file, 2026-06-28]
STL/Motorhousing Cover with Handle.stl
35.2 x 88.1 x 78.6

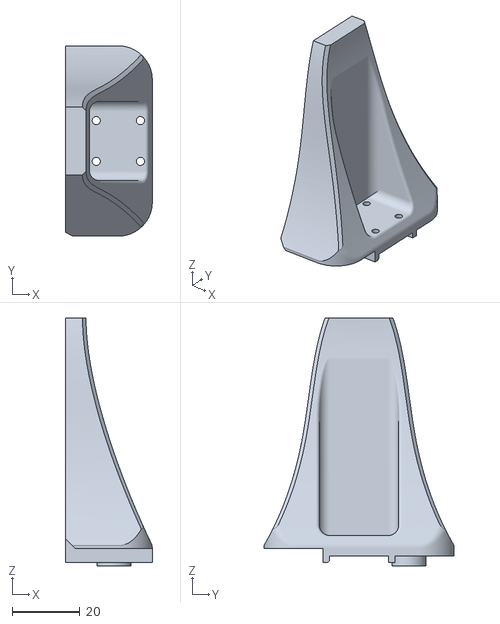
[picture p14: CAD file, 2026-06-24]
STL/Finger_2.stl
25.5 x 56.0 x 73.0

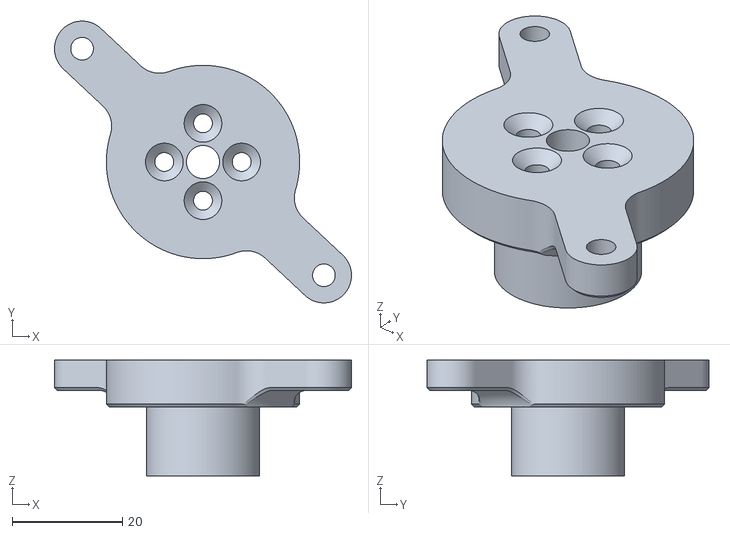
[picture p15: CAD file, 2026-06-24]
STL/Turnhead.stl
53.8 x 51.0 x 21.0

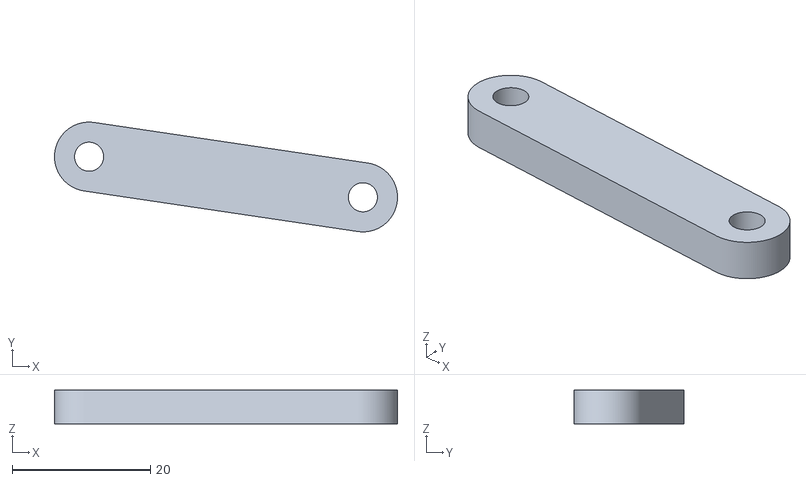
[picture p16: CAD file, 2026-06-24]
STL/Schwing Arm 2.stl
49.6 x 15.9 x 4.90

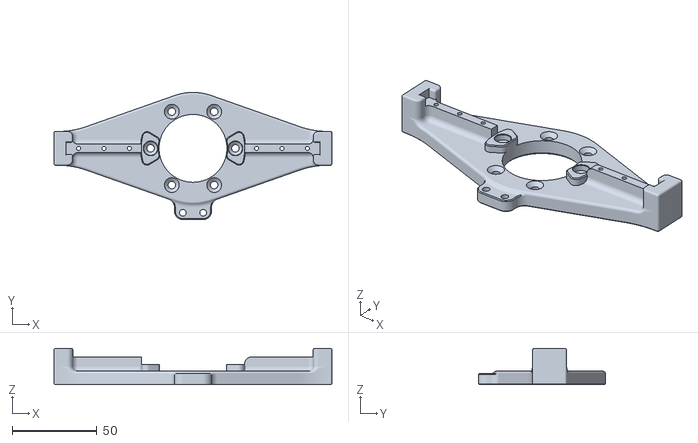
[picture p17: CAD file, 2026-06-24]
STL/Baseplate.stl
164.0 x 75.0 x 21.5

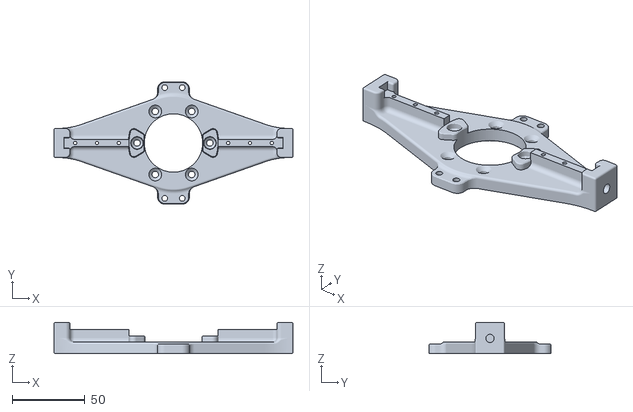
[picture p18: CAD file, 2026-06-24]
STL/Baseplate_Multi.stl
164.0 x 84.0 x 21.5

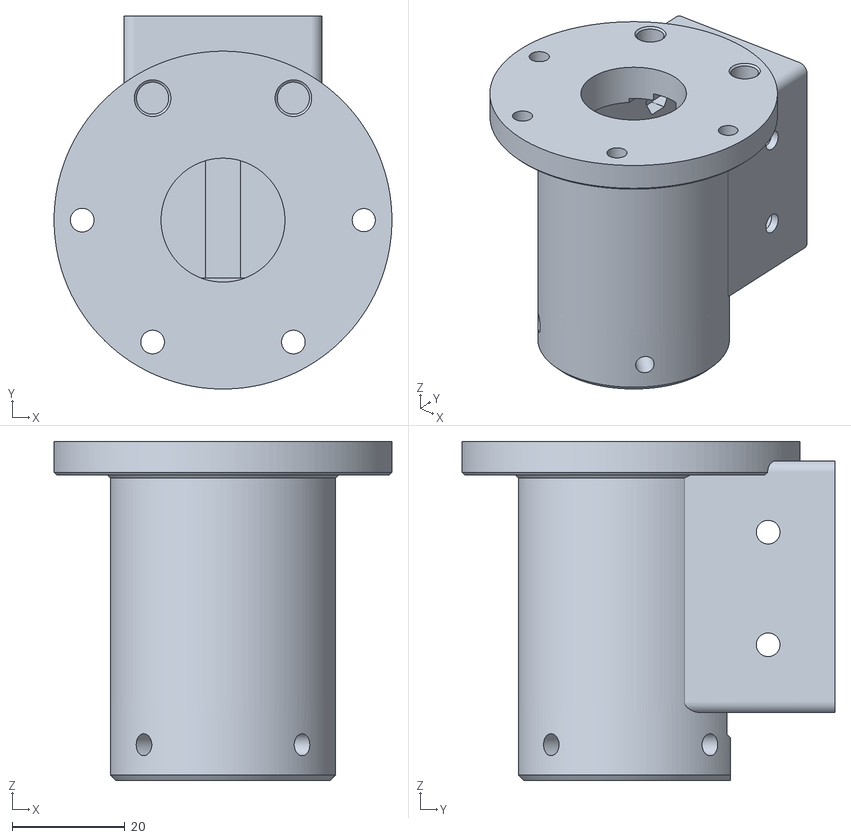
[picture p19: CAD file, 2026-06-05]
STL/Motorhousing.stl
60.0 x 66.2 x 60.2

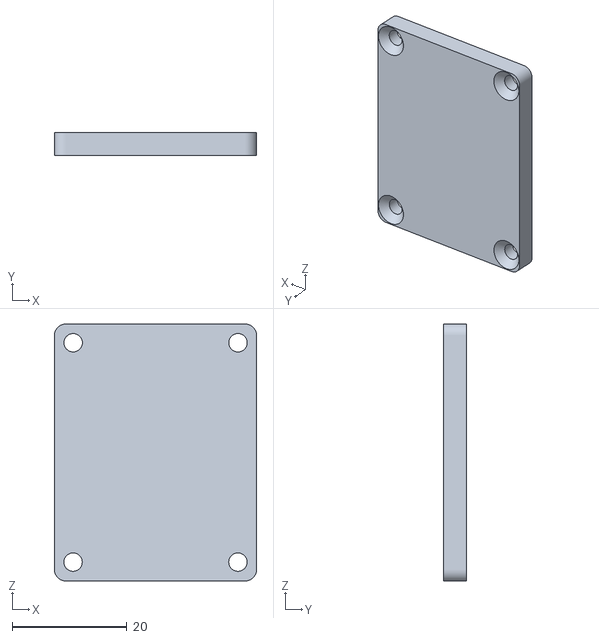
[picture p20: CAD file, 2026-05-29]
STL/Motorhousing Cover.stl
35.2 x 4.00 x 44.8

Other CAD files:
STL/Finger_1.stl
STL/Waveshare Serial Board DIN Rail Holder.stl
STL/DIN Rail Holder Serial Board.stl

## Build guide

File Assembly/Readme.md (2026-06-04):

# ST3215 Servo Gripper Assembly Guide








> Detaillierte Montageanleitung für den ST3215 Servo Gripper.
>
> Detailed assembly manual for the ST3215 Servo Gripper.

---

## Sprache / Language

- Deutsch: [Zur deutschen Anleitung springen](#de-start)
- English: [Jump to English guide](#en-start)

---

# Deutsch

[Zur Sprachauswahl](#language-selection)

## Inhaltsverzeichnis

- [Quick Facts](#de-quick-facts)
- [Benötigte Teile](#de-parts)
- [Werkzeuge](#de-tools)
- [Sicherheitshinweise](#de-safety)
- [Montage-Schritte](#de-steps)
- [Prüfung nach Montage](#de-check)
- [Troubleshooting](#de-troubleshooting)
- [Versionierung und Changelog](#de-versioning)
- [Mitwirken](#de-contributing)
- [Lizenz](#de-license)

---

## Quick Facts

| Thema | Details |
|---|---|
| Projekt | ST3215 Servo Gripper |
| Schwierigkeit | Mittel |
| Zeitbedarf | ca. 30 min |
| Version der Anleitung | v1.0 |
| Letztes Update | 2026-05-30 |

---

## Benötigte Teile

### 3D-Druck-Teile

- [ ] Grundplatte - Menge 1
- [ ] Motorgehäuse - Menge 1
- [ ] Motorgehäuse-Deckel - Menge 1
- [ ] Drehkranz - Menge 1
- [ ] Schwingen / Arme - Menge 2
- [ ] Greiferfinger - Menge 2
- [ ] Linearführung MGN7H 150 mm - Menge 1
- [ ] Führungswagen für MGN7H - Menge 2

### Elektronik

- [ ] Waveshare ST3215 Servo Motor - Menge 1
- [ ] Waveshare Serial Servo Driver - Menge 1

### Kleinteile

- [ ] M2 x 8 mm Zylinderkopfschrauben - Menge 8
- [ ] M2 x 20 mm Linsenkopfschrauben (Flat Head) - Menge 6
- [ ] M3 x 25 mm Senkkopfschrauben - Menge 4
- [ ] M3 Gewindeeinsätze (Einschmelzmutter) - Menge 6
- [ ] M3 Passschrauben (D1=4 mm, L1=6 mm, L2=4 mm) - Menge 4
- [ ] M4 x 6 mm Madenschrauben - Menge 5
- [ ] M4 x 12 mm Senkkopfschrauben - Menge 6
- [ ] M4 Muttern - Menge 4
- [ ] M4 Gewindeeinsätze (Einschmelzmutter) - Menge 2
- [ ] Servo-Zubehör-Set (Lieferumfang ST3215) - Menge 1

Gesamtüberblick

---

## Werkzeuge

- [ ] Innensechskantschlüssel 1.5 bis 4 mm
- [ ] Schraubendreher PH / Schlitz fein (z. B. 4 x 2.0)
- [ ] Schraubensicherung mittelfest (optional)
- [ ] Sekundenkleber (optional)
- [ ] Lötkolben oder Einschmelzhilfe für Gewindeeinsätze

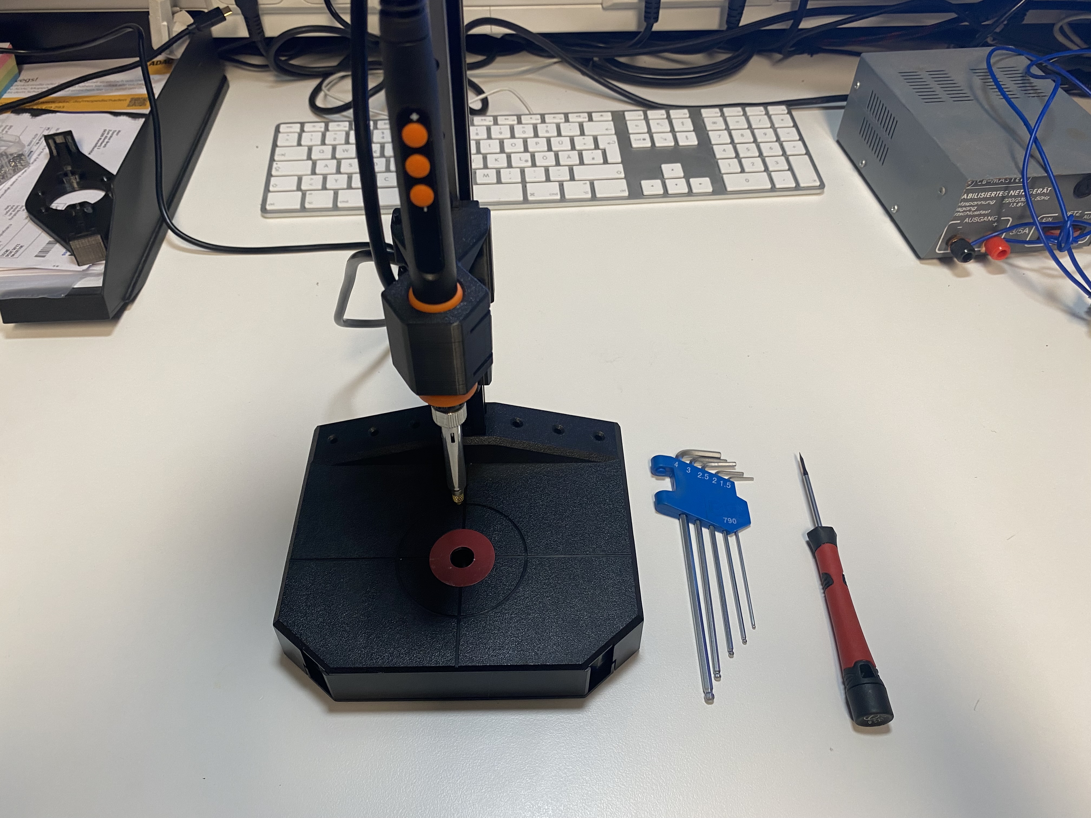
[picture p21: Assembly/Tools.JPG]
Werkzeug und Referenz


---

## Sicherheitshinweise

- Vor der Montage alle Stützstrukturen von den 3D-Druck-Teilen entfernen.
- Keine Gewalt anwenden: Bei Widerstand Ausrichtung und Passung prüfen.
- Elektrische Komponenten erst nach der mechanischen Montage bestromen.
- Bewegliche Bereiche auf Quetschstellen kontrollieren.
- Vorsicht beim Einschmelzen von Gewindeeinsätzen: Verbrennungsgefahr.

---

## Montage-Schritte

### Schritt 01
Schritt 01

Beschreibung: M4 Gewinde-Einsätze in Motorgehäuse einschmelzen.

Wichtige Hinweise:
- Darauf achten dass, die Gewinde bündig mit der Oberfläche abschließen.

### Schritt 02
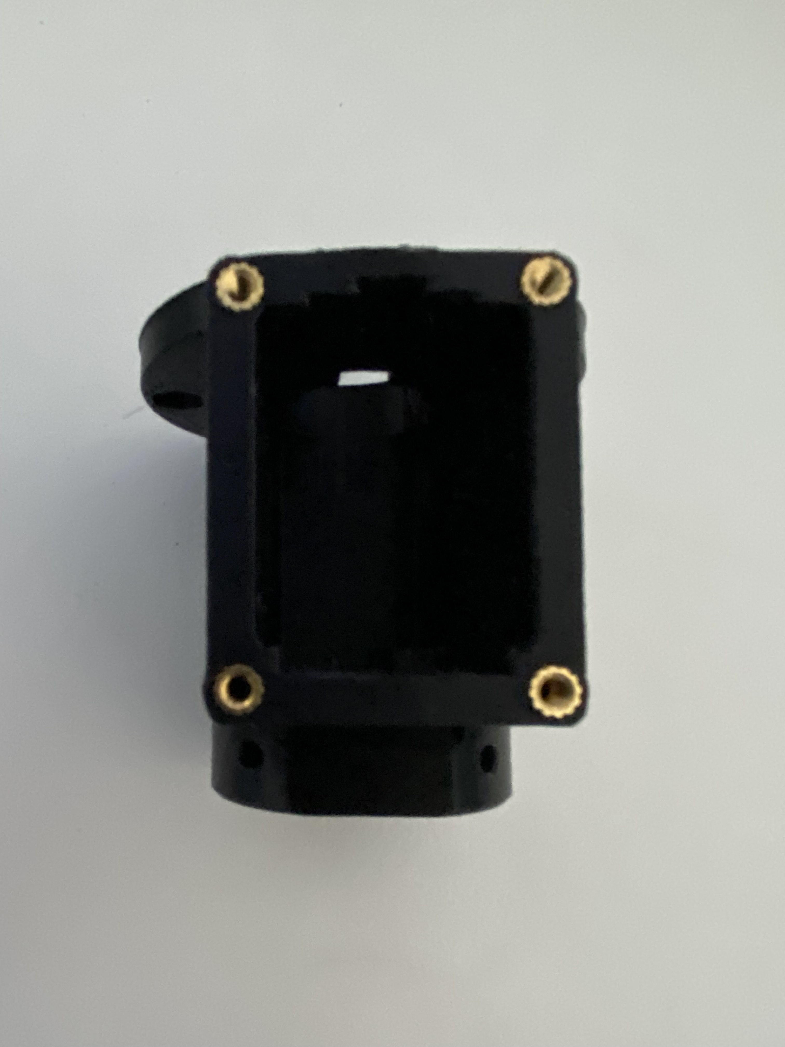
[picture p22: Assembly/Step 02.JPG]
Schritt 02


Beschreibung: M3 Gewinde-Einsätze in Motorgehäuse einschmelzen.

Wichtige Hinweise:
- Darauf achten dass, die Gewinde bündig mit der Oberfläche abschließen.
- Darauf achten dass, die Wand nicht ausbricht (dünne Wandstärke).

### Schritt 03
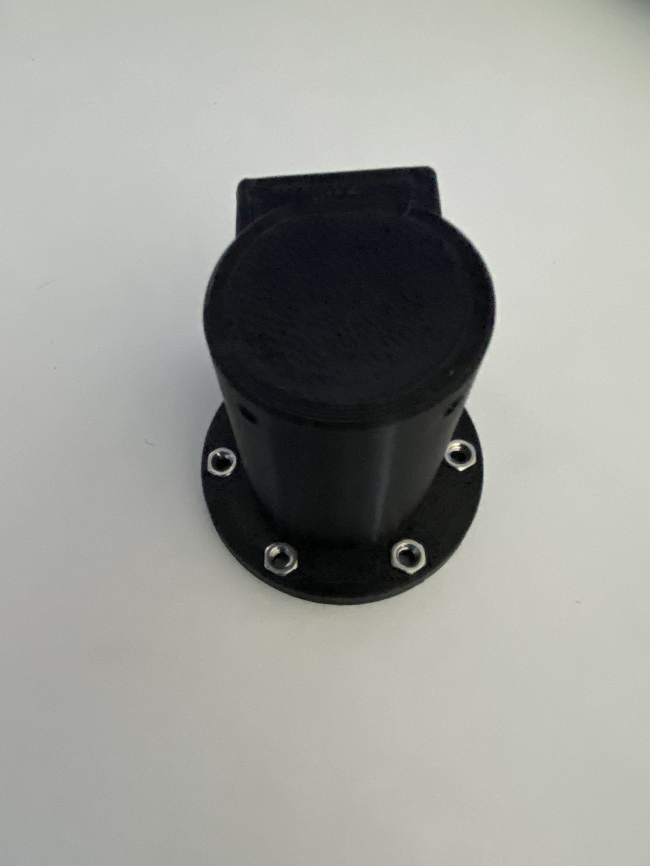
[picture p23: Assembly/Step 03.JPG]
Schritt 03


Beschreibung: M4 Muttern in Motorgehäuse einlegen und ggf. mit Sekundenkleber fixieren.

Wichtige Hinweise:
- Bei Verwendung von Sekundekleber, darauf achten, dass die Gewinde nicht verklebt werden.

### Schritt 04
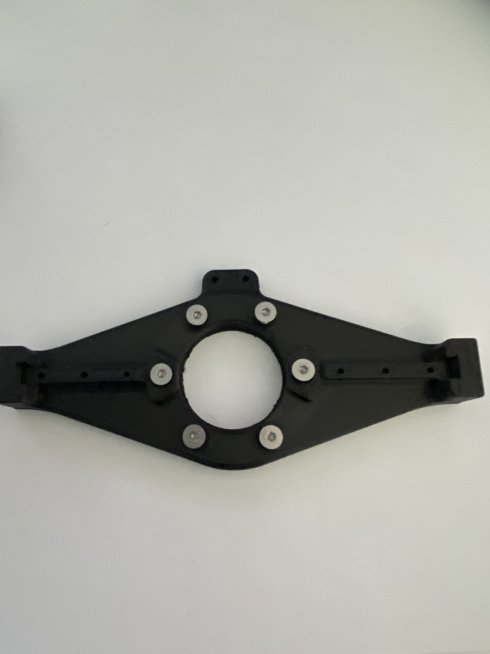
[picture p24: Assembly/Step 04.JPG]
Schritt 04


Beschreibung: M4x12 Senkkopf Schrauben in die Grundplatte einlegen.

Wichtige Hinweise:
- Falls die Schrauben schwergängig in die Bohrungen rein gehen, dann mit einem Bohrer (4.0 - 4.5) die Bohrung etwas aufweiten.

### Schritt 05
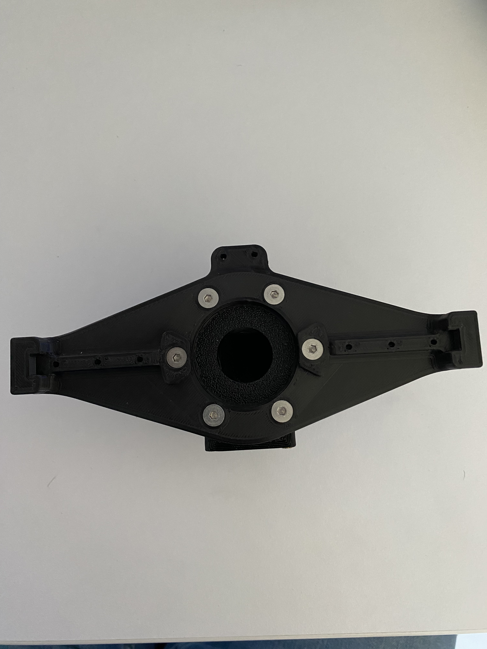
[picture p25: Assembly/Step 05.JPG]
Schritt 05


Beschreibung: Motorgehäuse mit Grundplatte verschrauben.

Wichtige Hinweise:
- Darauf achten, dass die Gewinde leichtgängig greifen - nicht schief eindrehen.

### Schritt 06
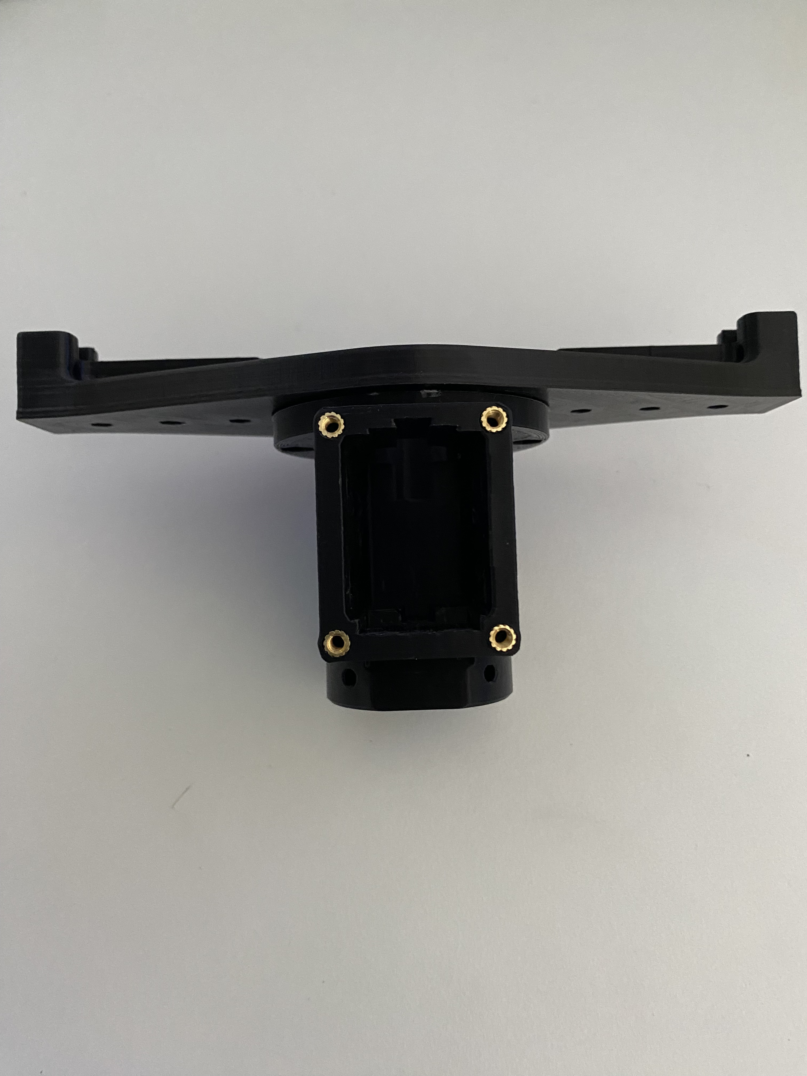
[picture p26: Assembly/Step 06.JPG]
Schritt 06


Beschreibung: Die fertig verschraubte Baugruppe sollte nun so aussehen.

Wichtige Hinweise:
- Es sollte kein Spalt zwischen den Bauteilen sein - falls doch, dann sind die Schmelz-Einsätze vermutlich nicht tief genug eingeschmolzen.

### Schritt 07
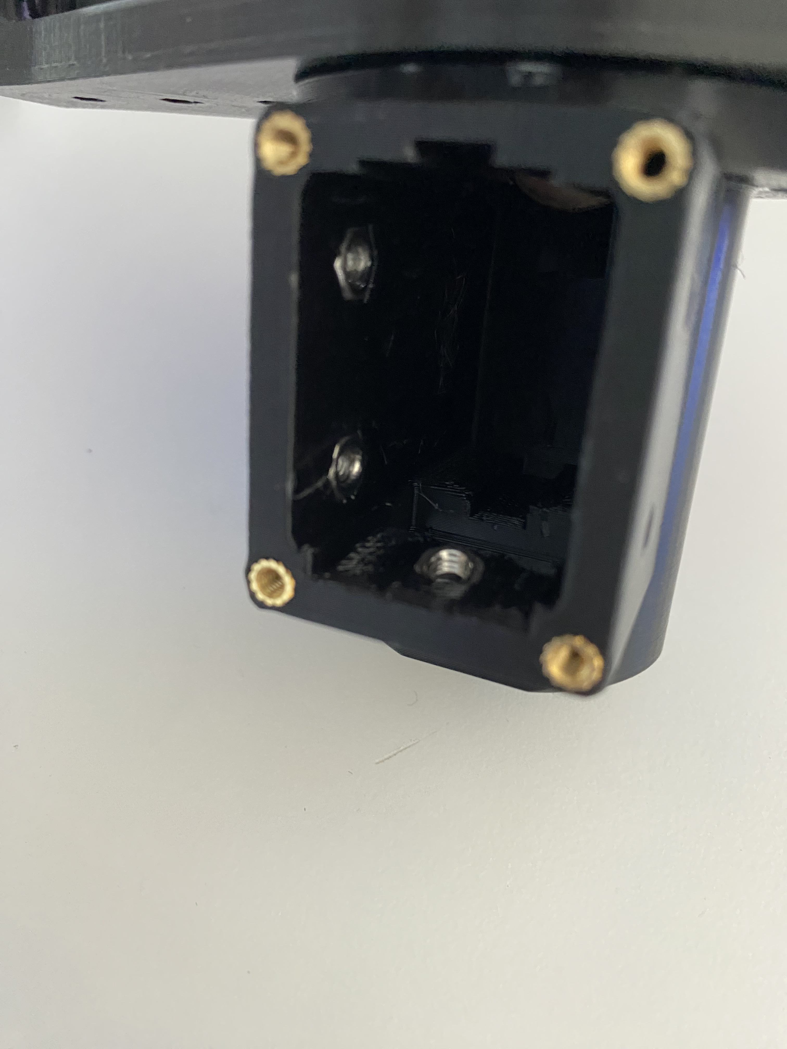
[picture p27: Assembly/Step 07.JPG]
Schritt 07


Beschreibung: M4 Muttern in Motorgehäuse einlegen und ggf. mit Sekundenkleber fixieren.

Wichtige Hinweise:
- Bei Verwendung von Sekundekleber, darauf achten, dass die Gewinde nicht verklebt werden.

### Schritt 08
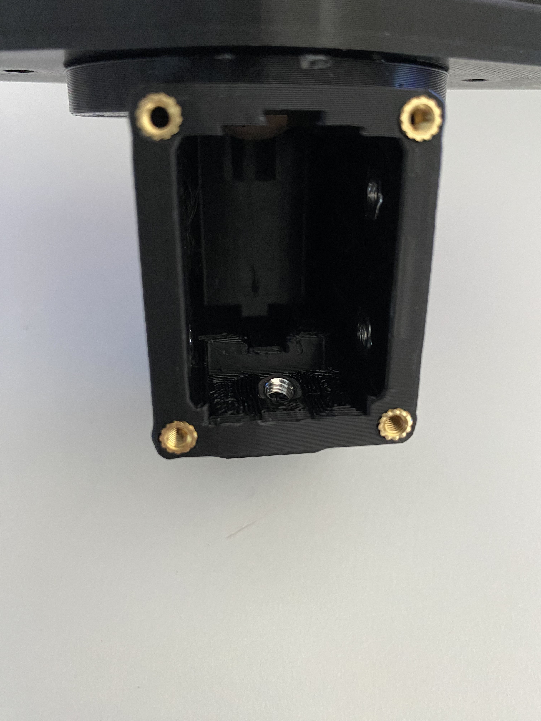
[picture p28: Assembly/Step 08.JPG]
Schritt 08


Beschreibung: M4 Muttern in Motorgehäuse einlegen und ggf. mit Sekundenkleber fixieren.

Wichtige Hinweise:
- Bei Verwendung von Sekundekleber, darauf achten, dass die Gewinde nicht verklebt werden.

### Schritt 09
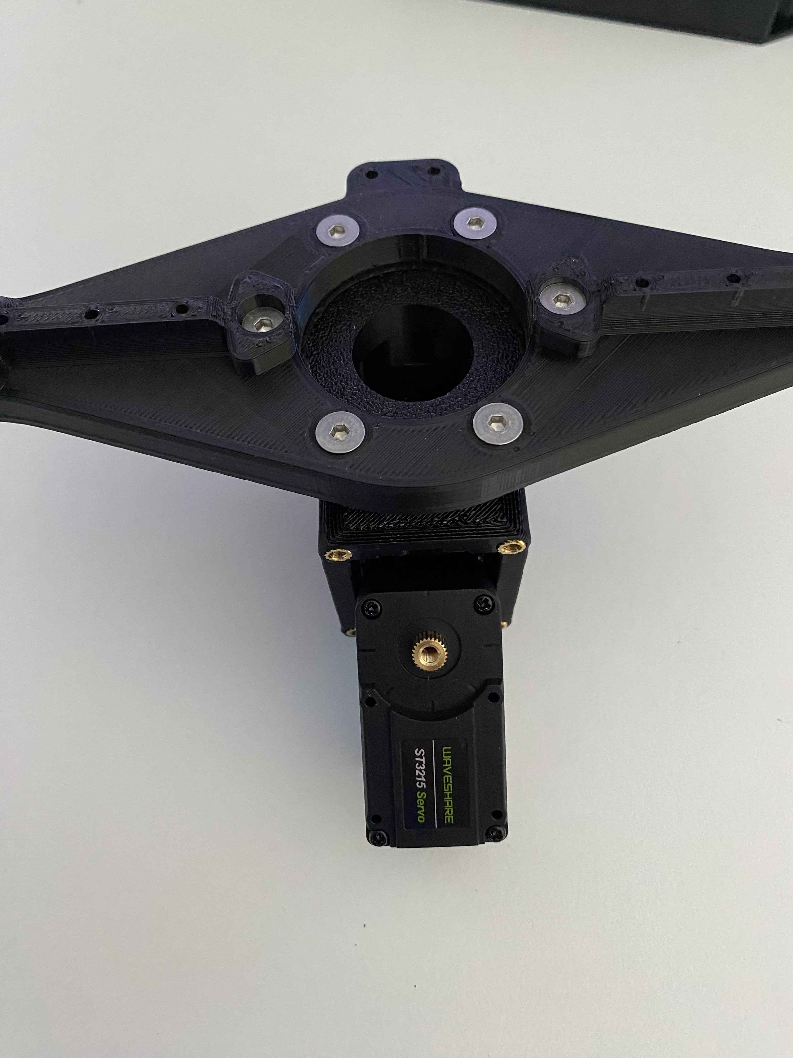
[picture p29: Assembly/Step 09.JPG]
Schritt 09


Beschreibung: Servo Motor in der Motorgehäuse einlegen.

Wichtige Hinweise:
- Darauf achten, dass der Zahnkranz nach oben zur Öffnung in der Grundplatte zeigt.

### Schritt 10
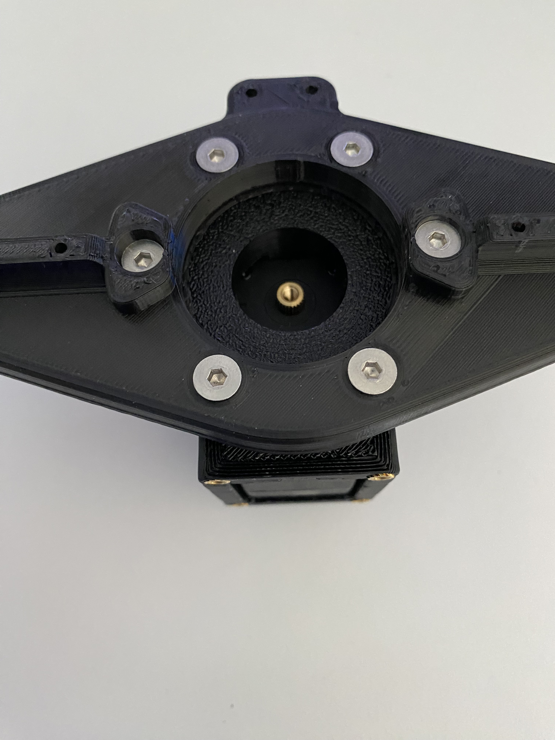
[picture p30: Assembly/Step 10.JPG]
Schritt 10


Beschreibung: Motor komplett einschieben.

Wichtige Hinweise:
- Darauf achten, dass der Motor bis Anschlag in das Gehäuse eingebracht ist.

### Schritt 11
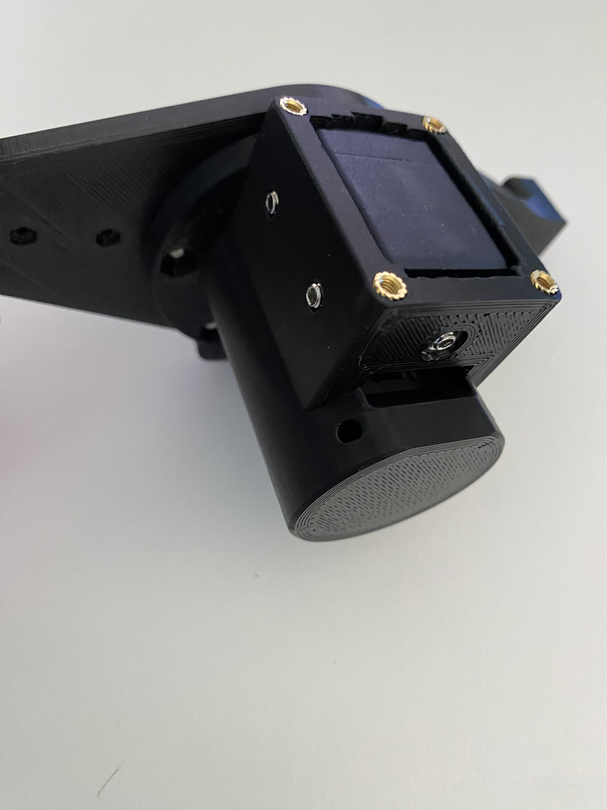
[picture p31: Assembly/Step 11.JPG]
Schritt 11


Beschreibung: M4x6 Madenschrauben eindrehen und Motor festklemmen.

Wichtige Hinweise:
- Motor mittig ausrichten.
- Darauf achten, dass der Motor nicht zu locker und nicht zu fest geklemmt wird.

### Schritt 12
Schritt 12

Beschreibung: M4x6 Madenschrauben eindrehen und Motor festklemmen.

Wichtige Hinweise:
- Darauf achten, dass der Motor mittig ausgerichtet ist.
- Darauf achten, dass der Motor nicht zu locker und nicht zu fest geklemmt wird.

### Schritt 13
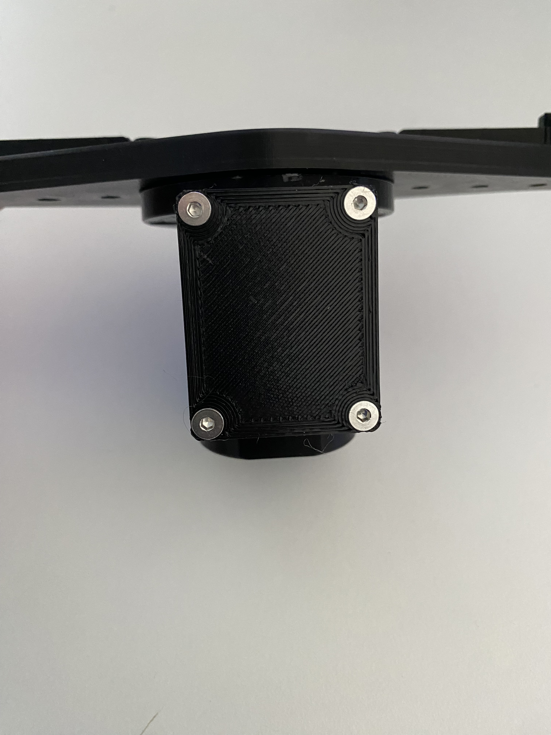
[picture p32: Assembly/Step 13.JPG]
Schritt 13


Beschreibung: Deckel des Motorgehäuse mit M3x8 Senkkopf Schrauben montieren.

Wichtige Hinweise:
- Darauf achten, dass der Deckel bündig abschließt.
- Es sollte kein Spalt zwischen den Bauteilen sein - falls doch, dann sind die Schmelz-Einsätze vermutlich nicht tief genug eingeschmolzen.

### Schritt 14
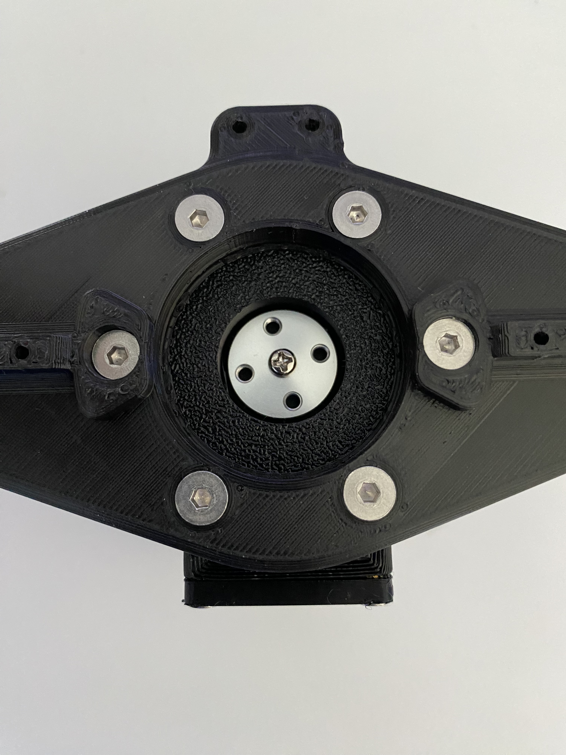
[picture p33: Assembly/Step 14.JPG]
Schritt 14


Beschreibung: Motor-Ritzel auf Servo Motor Welle montieren.

Wichtige Hinweise:
- Darauf achten, dass das Motor-Ritzel beim Aufstecken in die Verzahnung rutscht.

### Schritt 15
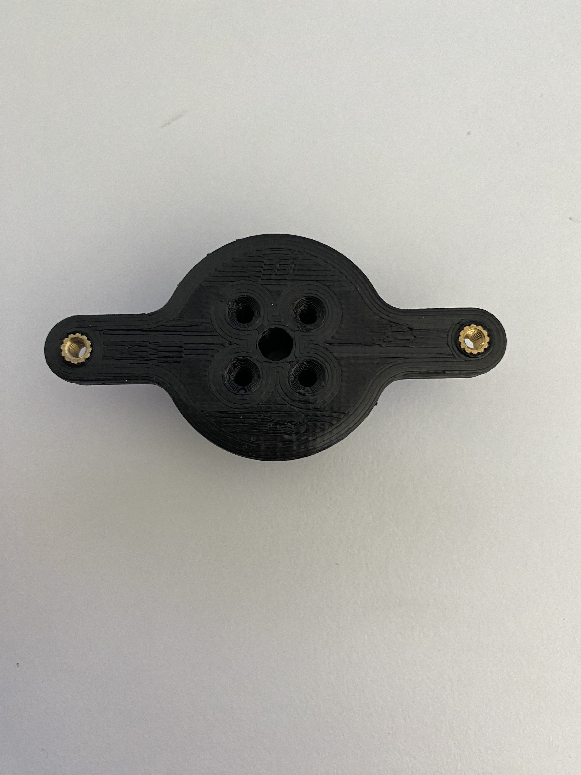
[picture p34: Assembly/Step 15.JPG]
Schritt 15


Beschreibung: M3 Gewinde-Einsätze in Drehkranz einschmelzen.

Wichtige Hinweise:
- Darauf achten dass, die Gewinde bündig mit der Oberfläche abschließen.

### Schritt 16
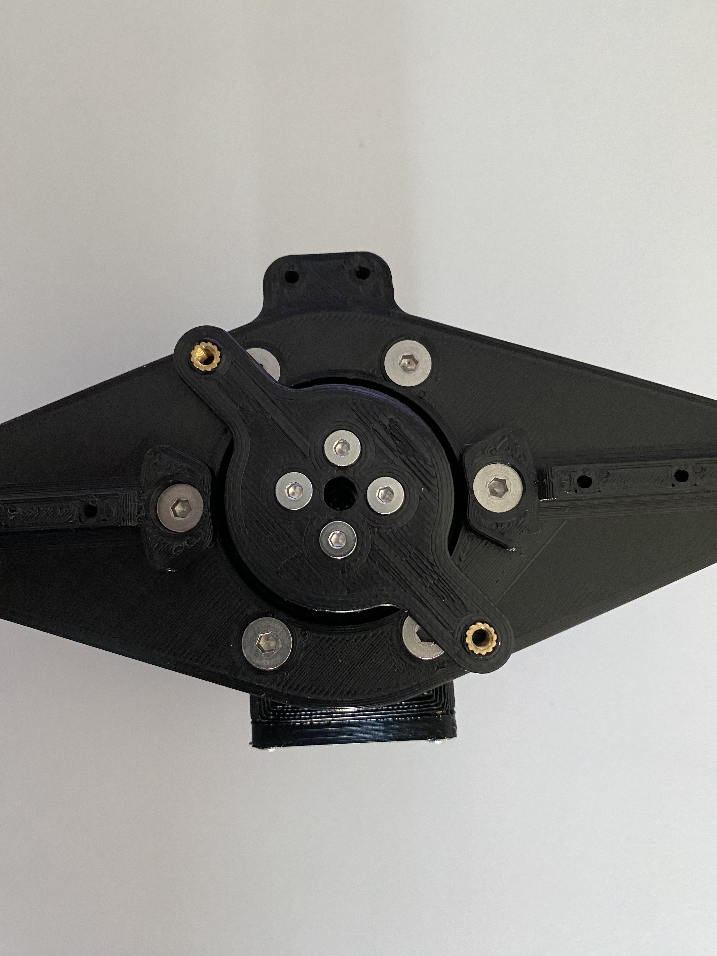
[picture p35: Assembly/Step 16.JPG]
Schritt 16


Beschreibung: Drehkranz mit M3x25 Senkkopf Schrauben auf dem Motor-Ritzel montieren.

Wichtige Hinweise:
- Darauf achten, dass die Schraubenköpfe komplett versenkt sind - falls dies nicht der Fall ist, muss nachgesenkt werden, da die Schraubenköpfe sonst später an der Linearführung hängen bleiben.

### Schritt 17
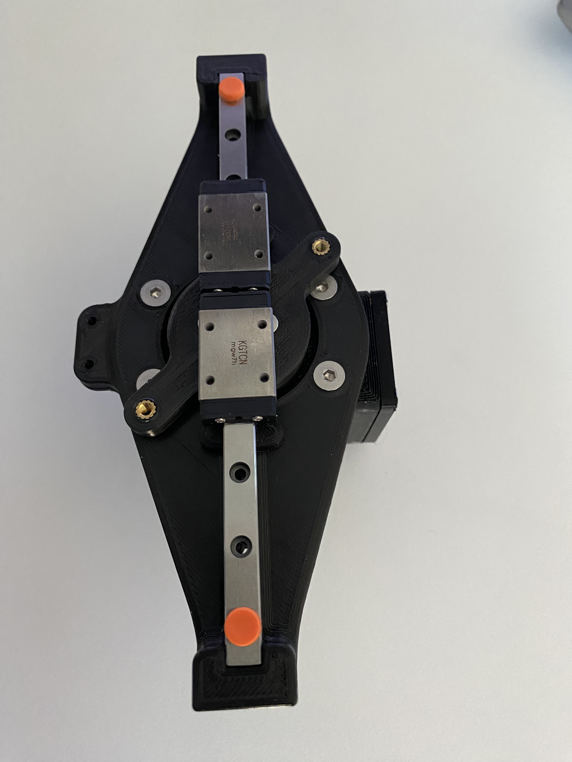
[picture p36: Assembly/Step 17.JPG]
Schritt 17


Beschreibung: Linearführung in Grundplatte einlegen.

Wichtige Hinweise:
- Darauf achen, dass die Führungswagen nicht aus der Schiene raus gehen - da sonst Kugeln verloren gehen können. Dafür die orangenen Begrenzungsstopfen während der Montage in den Schienen belassen.

### Schritt 18
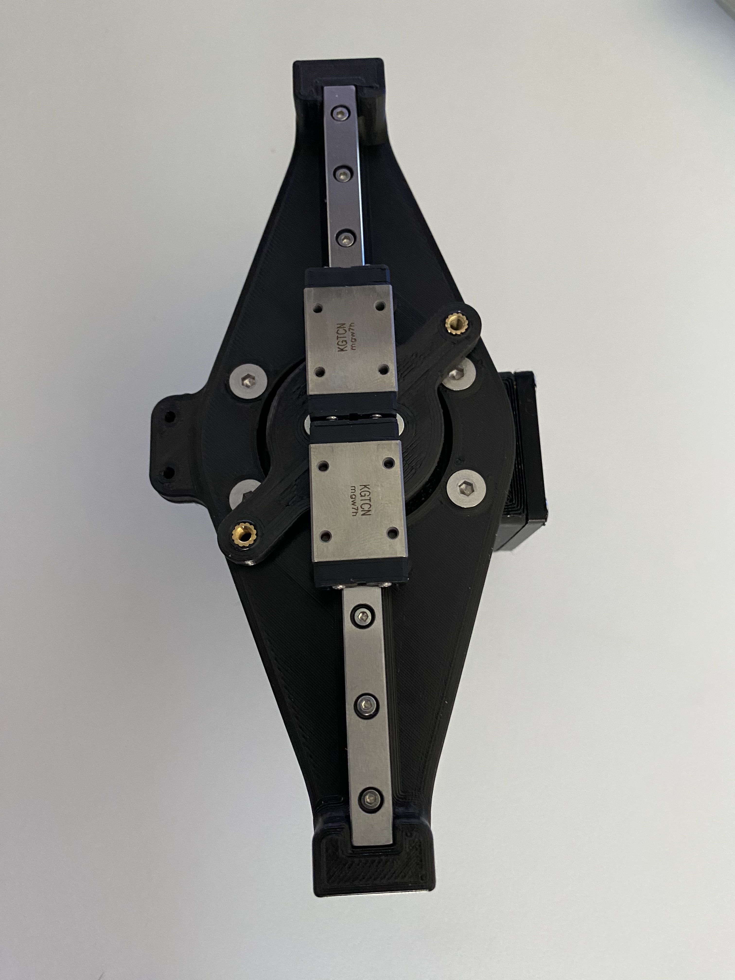
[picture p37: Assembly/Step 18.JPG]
Schritt 18


Beschreibung: M2x20 Flachkopf Schrauben durch die Führungsschiene stecken.

Wichtige Hinweise:
- Darauf achten, dass die Schraubenköpfe nicht über die Schiene hinaus ragen, da die Führungswagen sonst dran hängen bleiben.

### Schritt 19
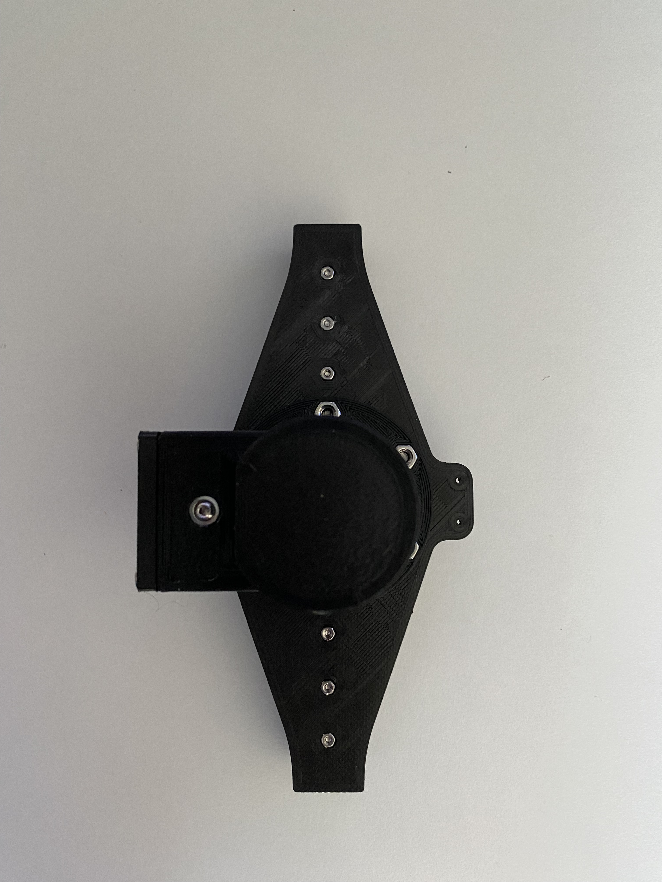
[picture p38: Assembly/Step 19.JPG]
Schritt 19


Beschreibung: M2 Muttern in Grundplatte einlegen, ggf. mit Sekundenkleber fixieren, und die M2x20 Schrauben von der anderen Seite verschrauben.

Wichtige Hinweise:
- Bei Verwendung von Sekundekleber, darauf achten, dass die Gewinde nicht verklebt werden.

### Schritt 20
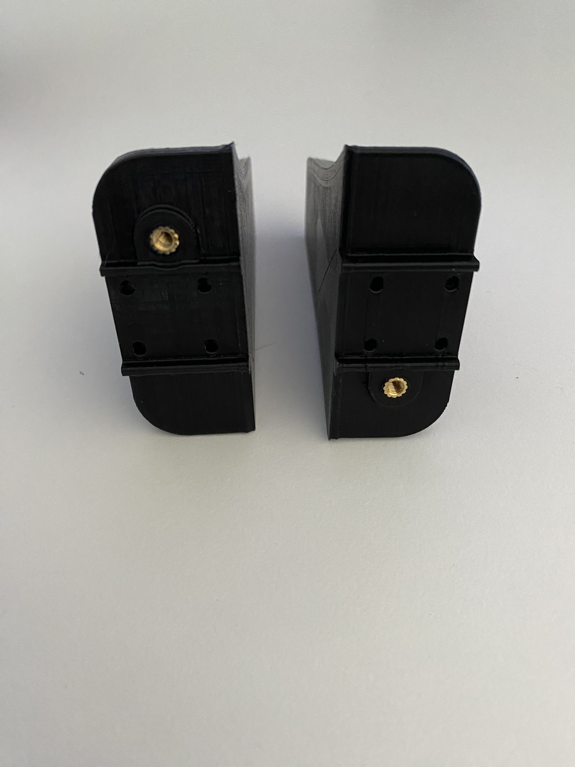
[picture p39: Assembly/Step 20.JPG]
Schritt 20


Beschreibung: M3 Gewinde-Einsätze in Greifer-Finger einschmelzen.

Wichtige Hinweise:
- Darauf achten dass, die Gewinde bündig mit der Oberfläche abschließen.

### Schritt 21
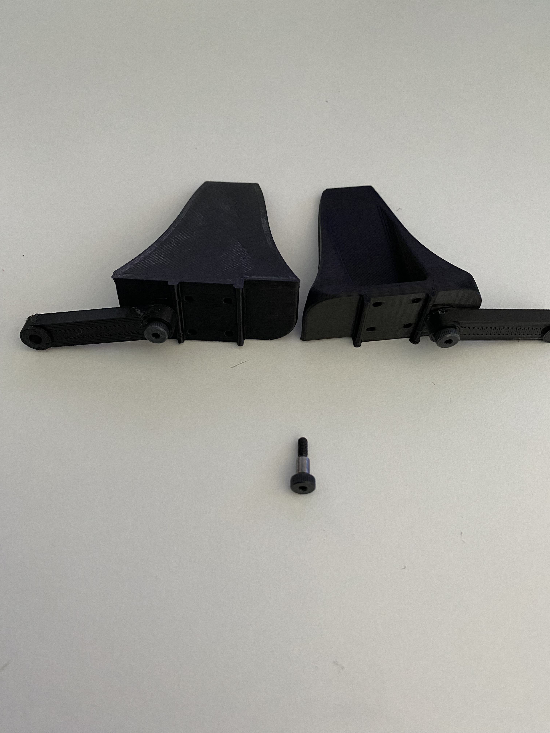
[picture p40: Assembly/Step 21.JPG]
Schritt 21


Beschreibung: Schwingen / Arme mit M3x10 Pass-Schrauben an den Greifer-Fingern verschrauben.

Wichtige Hinweise:
- Darauf achten, dass sich die Schwingen / Arme leichtgängig in der Passung bewegen.
- Falls zu viel Spiel ist, ggf. die Gewinde der Pass-Schrauben etwas kürzen.

### Schritt 22
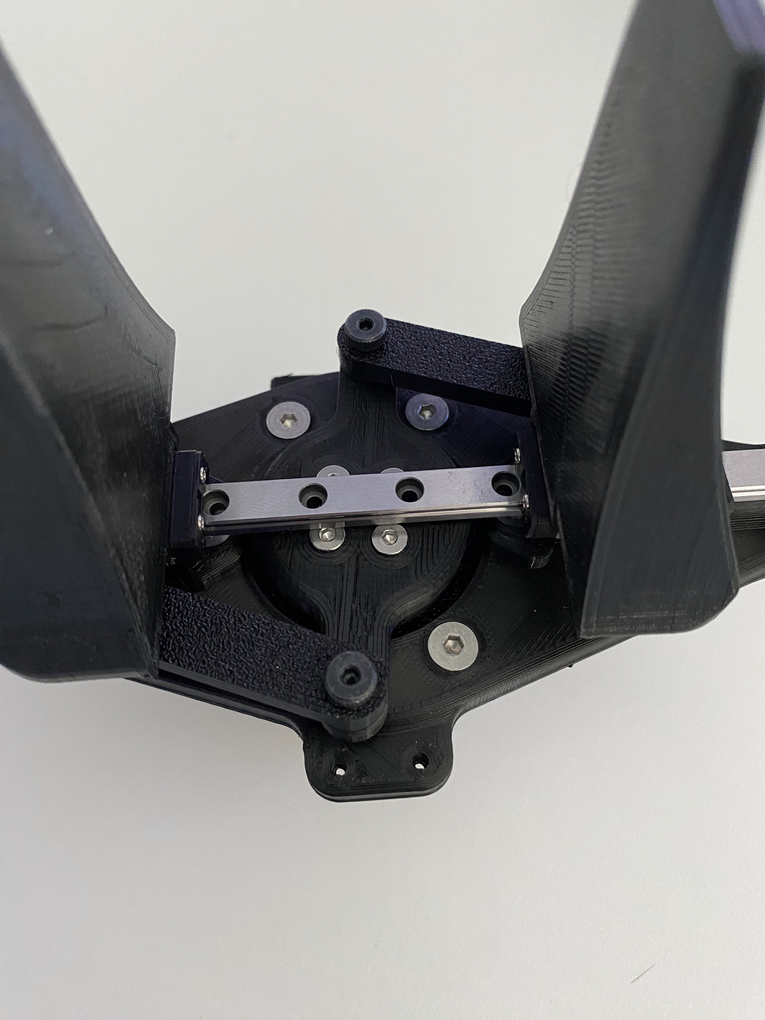
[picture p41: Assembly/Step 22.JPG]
Schritt 22


Beschreibung: Greifer-Finger auf Führungswagen aufsetzen und Schwingen / Arme mit dem Motor-Drehkranz verschrauben.

Wichtige Hinweise:
- Darauf achten, dass sich die Schwingen / Arme leichtgängig in der Passung bewegen.
- Darauf achten, dass das Gewinde nicht nach unten übersteht und an der Basisplatte schleift - ggf. die Gewinde der Pass-Schrauben etwas kürzen.

### Schritt 23
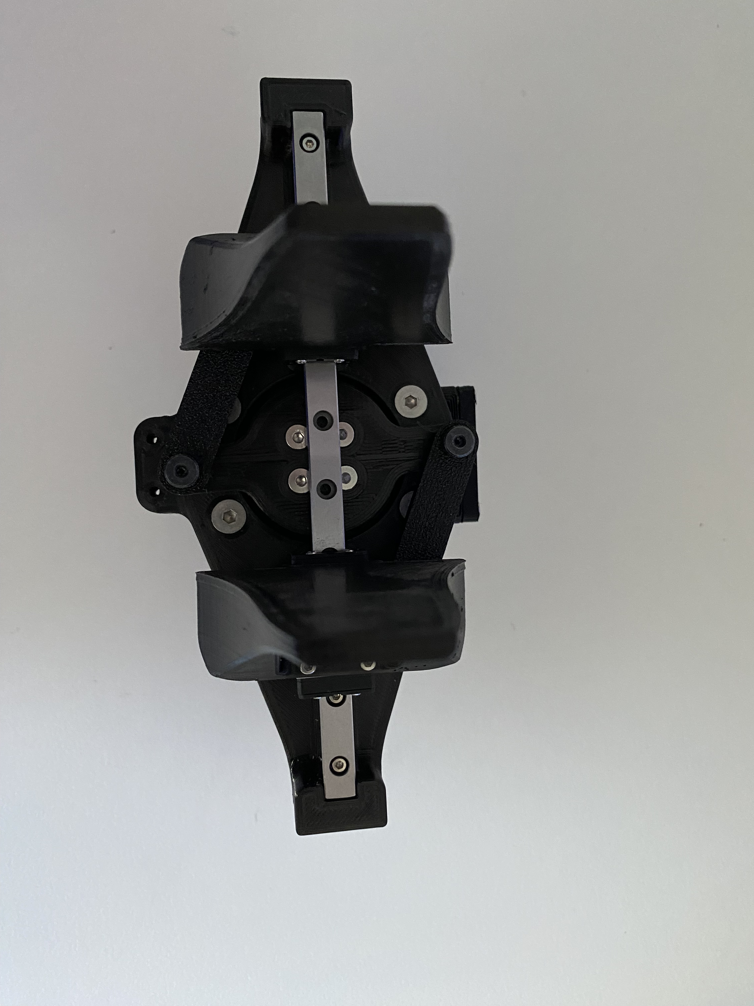
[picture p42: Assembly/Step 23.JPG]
Schritt 23


Beschreibung: Greifer-Finger mit M3x8 Schrauben in den Führungswagen verschrauben.

Wichtige Hinweise:
- Darauf achten, dass die Finger fest mit den Führungswagen verschraubt sind und ein Kraftschluss vorhanden ist - ggf. Gewinde kürzen, falls das Gewinde bereits vor einem Kraftschluss am Anschlag ist.

### Schritt 24
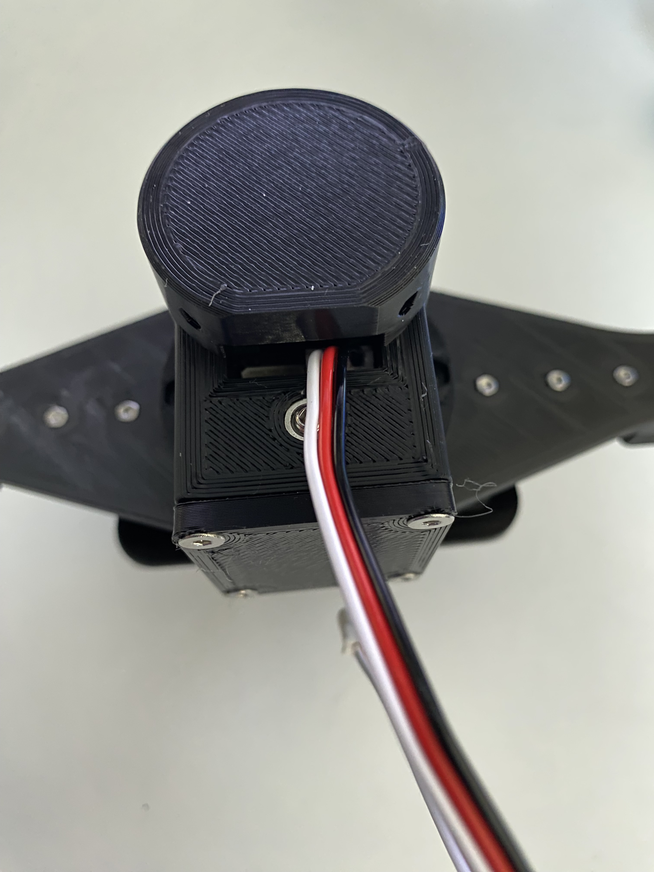
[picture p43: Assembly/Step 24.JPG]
Schritt 24


Beschreibung: Motorkabel in Servo Motor einstecken.

Wichtige Hinweise:
- Darauf achten, dass die Stecker in die richtige Richtung gedreht sind.
- Ggf. das Kabel-Ende etwas vorbiegen, damit man den Stecker mit Hilfe des Kabels Richtung Buchse bewegen kann.
- Zum Einstecken des Steckers mit einem Schraubendreher etwas nachhelfen und den Stecker auf Anschlag drücken.

### Schritt 25
Schritt 25

Beschreibung: Motor-Kabel in Steuerplatine einstecken.

Wichtige Hinweise:
- Darauf achten, dass die Steuerplatine ausgeschaltet ist und nicht unter Spannung gearbeitet wird.

---

## Prüfung nach Montage

- [ ] Alle Schraubverbindungen geprüft
- [ ] Beweglichkeit ohne Klemmen sichergestellt
- [ ] Elektrische Leitungen fest aufgesteckt
- [ ] Endanschläge und Nullposition prüfbar
- [ ] Erste Funktionsfahrt ohne Last erfolgreich

---

## Troubleshooting

| Problem | Mögliche Ursache | Lösung |
|---|---|---|
| Finger laufen schwergängig | Verspannte Mechanik / Verschraubung | Schrauben lösen, ausrichten, erneut anziehen |
| Spiel im Greifer | Toleranzen zu groß | Kritische Teile mit engeren Toleranzen neu drucken |
| Motor wird warm ohne Last | Mechanischer Widerstand zu hoch | Mechanik entlasten, Freigang prüfen |

---

## Versionierung und Changelog

- [CHANGELOG.md](../CHANGELOG.md)

---

## Mitwirken

Beiträge zur Verbesserung von Bildern, Formulierungen, Reihenfolge und Sicherheitshinweisen sind willkommen.

---

## Lizenz

MIT — siehe [LICENSE](../LICENSE)

[Zur Sprachauswahl](#language-selection)

Donate with PayPal (https://www.paypal.com/donate/?hosted_button_id=ERN6VH9WA95J6)

---

# English

[Back to language selection](#language-selection)

## Table of Contents

- [Quick Facts](#en-quick-facts)
- [Required Parts](#en-parts)
- [Tools](#en-tools)
- [Safety Notes](#en-safety)
- [Assembly Steps](#en-steps)
- [Post-Assembly Check](#en-check)
- [Troubleshooting](#en-troubleshooting)
- [Versioning and Changelog](#en-versioning)
- [Contributing](#en-contributing)
- [License](#en-license)

---

## Quick Facts

| Topic | Details |
|---|---|
| Project | ST3215 Servo Gripper |
| Difficulty | Medium |
| Assembly Time | About 30 min |
| Guide Version | v1.0 |
| Last Update | 2026-05-30 |

---

## Required Parts

### 3D Printed Parts

- [ ] Base plate - Qty 1
- [ ] Motor housing - Qty 1
- [ ] Motor housing cover - Qty 1
- [ ] Turntable gear - Qty 1
- [ ] Swing arms - Qty 2
- [ ] Gripper fingers - Qty 2
- [ ] MGN7H linear rail, 150 mm - Qty 1
- [ ] Carriages for MGN7H - Qty 2

### Electronics

- [ ] Waveshare ST3215 servo motor - Qty 1
- [ ] Waveshare serial servo driver - Qty 1

### Fasteners and Small Parts

- [ ] M2 x 8 mm socket head screws - Qty 8
- [ ] M2 x 20 mm flat head screws - Qty 6
- [ ] M3 x 25 mm countersunk screws - Qty 4
- [ ] M3 heat-set inserts - Qty 6
- [ ] M3 shoulder screws (D1=4 mm, L1=6 mm, L2=4 mm) - Qty 4
- [ ] M4 x 6 mm set screws - Qty 5
- [ ] M4 x 12 mm countersunk screws - Qty 6
- [ ] M4 nuts - Qty 4
- [ ] M4 heat-set inserts - Qty 2
- [ ] Servo accessory set (included with ST3215) - Qty 1

Overview

---

## Tools

- [ ] Hex keys, 1.5 to 4 mm
- [ ] Small screwdriver set
- [ ] Medium thread locker (optional)
- [ ] Super glue (optional)
- [ ] Soldering iron or insert press tool for heat-set inserts

Tools and reference

---

## Safety Notes

- Remove all support material from printed parts before assembly.
- Do not force-fit parts. Check alignment and tolerances first.
- Power electronics only after mechanical assembly is complete.
- Watch pinch points around moving gripper elements.
- Heat-set inserts and nearby material can cause burns.

---

## Assembly Steps

### Step 01
Step 01

Description: Install M4 heat-set inserts into the motor housing.

Key notes:
- Keep inserts flush with the surface.

### Step 02
Step 02

Description: Install M3 heat-set inserts into the motor housing.

Key notes:
- Keep inserts flush.
- Avoid overheating thin wall sections.

### Step 03
Step 03

Description: Place M4 nuts into the housing pockets and optionally secure with super glue.

Key notes:
- Do not contaminate threads with glue.

### Step 04
Step 04

Description: Insert M4 x 12 countersunk screws into the base plate.

Key notes:
- If fit is too tight, lightly ream holes to about 4.0 to 4.5 mm.

### Step 05
Step 05

Description: Fasten the motor housing to the base plate.

Key notes:
- Start screws straight to avoid cross-threading.

### Step 06
Step 06

Description: Check the assembled subunit for proper seating.

Key notes:
- No visible gap between mating parts.
- If gaps remain, set inserts deeper.

### Step 07
Step 07

Description: Insert additional M4 nuts into the designated pockets.

Key notes:
- Keep threads free of glue.

### Step 08
Step 08

Description: Place remaining M4 nuts in the specified positions.

Key notes:
- Ensure nuts sit flat without stress.

### Step 09
Step 09

Description: Place the servo motor into the motor housing.

Key notes:
- Align gear spline toward the opening in the base plate.

### Step 10
Step 10

Description: Push the servo fully into position.

Key notes:
- Servo must sit at the hard stop.

### Step 11
Step 11

Description: Tighten M4 x 6 set screws to clamp the servo.

Key notes:
- Center the servo.
- Do not overtighten.

### Step 12
Step 12

Description: Finalize clamp alignment and tighten evenly.

Key notes:
- Servo should be fixed without deformation.

### Step 13
Step 13

Description: Mount the housing cover using M3 screws.

Key notes:
- Cover must sit flush.
- No gap between cover and housing.

### Step 14
Step 14

Description: Install the motor pinion on the servo shaft.

Key notes:
- Engage the teeth cleanly.

### Step 15
Step 15

Description: Install M3 heat-set inserts into the turntable gear.

Key notes:
- Keep inserts flush.

### Step 16
Step 16

Description: Attach turntable gear to pinion using M3 x 25 countersunk screws.

Key notes:
- Fully countersink screw heads.
- Re-countersink if needed to avoid rail interference.

### Step 17
Step 17

Description: Place linear rail into the base plate.

Key notes:
- Do not slide carriages off the rail.
- Keep orange shipping retainers installed until final handling.

### Step 18
Step 18

Description: Insert M2 x 20 screws through the rail.

Key notes:
- Screw heads must not protrude beyond rail profile.

### Step 19
Step 19

Description: Insert M2 nuts into base plate and fasten M2 x 20 screws.

Key notes:
- Use a tiny amount of glue only if needed.
- Keep threads clean.

### Step 20
Step 20

Description: Install M3 heat-set inserts into gripper fingers.

Key notes:
- Keep inserts flush.

### Step 21
Step 21

Description: Attach swing arms to gripper fingers with M3 shoulder screws.

Key notes:
- Joints must move smoothly.
- Adjust screw length if excessive play occurs.

### Step 22
Step 22

Description: Place gripper fingers on carriages and connect arms to the turntable.

Key notes:
- Thread ends must not rub on base plate.
- Shorten screws if required.

### Step 23
Step 23

Description: Fasten gripper fingers to carriages using M3 x 8 screws.

Key notes:
- Ensure firm mechanical lock.
- Check screw length if clamp force is missing.

### Step 24
Step 24

Description: Connect motor cable to the servo.

Key notes:
- Confirm connector orientation.
- Push connector fully in.

### Step 25
Step 25

Description: Connect motor cable to the control board.

Key notes:
- Connect only while system is unpowered.

---

## Post-Assembly Check

- [ ] All screw joints verified
- [ ] Smooth movement without binding
- [ ] Electrical connectors fully seated
- [ ] End stops and zero position reachable
- [ ] First no-load test successful

---

## Troubleshooting

| Problem | Possible Cause | Fix |
|---|---|---|
| Fingers move roughly | Mechanical preload / misalignment | Loosen screws, realign, retighten |
| Gripper has play | Part tolerances too loose | Reprint critical parts with tighter tolerance |
| Motor heats up without load | Mechanical friction too high | Reduce preload, verify free movement |

---

## Versioning and Changelog

- [CHANGELOG.md](../CHANGELOG.md)

---

## Contributing

Contributions improving images, wording, sequence, and safety notes are welcome.

---

## License

MIT — see [LICENSE](../LICENSE)

[Back to language selection](#language-selection)

Donate with PayPal (https://www.paypal.com/donate/?hosted_button_id=ERN6VH9WA95J6)

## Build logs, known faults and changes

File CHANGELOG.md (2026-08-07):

# Changelog

All notable changes to this project will be documented in this file.

Format: [Keep a Changelog](https://keepachangelog.com/en/1.0.0/)
Versioning: [Semantic Versioning](https://semver.org/spec/v2.0.0.html)

## [1.0.11] — 2026-08-07

### Added
- Added a Python TCP/IP bridge example that enables remote control of a USB-connected servo board over TCP/IP.

## [1.0.10] — 2026-06-28

### Added
- Added SO-ARM-101 compatible motorhousing STL files:
	- `STL/Motorhousing SO-ARM-101.stl`

- Added `STL/Motorhousing Cover with Handle.stl`
- Added cam holder STL file: `STL/Cam Holder.stl`
- Added DIN rail ESP32 adapter STL file: `STL/DIN Rail Holder ESP32 Adapter.stl`
- Added SO-ARM-101 assembly preview image: `Assembly/SO-Arm-101.jpeg`

---

## [1.0.9] — 2026-06-24

### Added
- Added ESP32 Arduino firmware project (`Software/ESP32/TcpIp_Server`) for servo control via web UI and TCP/IP server.
- Added DIN rail holder CAD/STL assets to project documentation:
	- `Step/DIN Rail Holder Serial Board.step`
	- `STL/DIN Rail Holder Serial Board.stl`
	- `Assembly/DIN Rail Holder.jpeg`
- Added dedicated ESP32 documentation in `Software/ESP32/Readme.md`.

### Changed
- Updated `ReadMe.md` (DE/EN) to include DIN rail holder image preview and links for the new STEP/STL files.
- Updated `Software/Readme.md` (DE/EN) with a direct reference to the ESP32 firmware documentation.
- Expanded `Software/ESP32/Readme.md` with:
	- fixed, tested Arduino package/library version set

---

## [1.0.8] — 2026-06-05

### Changed
- Corrected some scew lengths in BOM list ( bill of material )
- Corrected the depth for the hex holes in the base plate, so that a M2x20 screw can be screwed in - before the screw was to short
- Corrected the hole diameter of the 4 flange holes ( it is now for M3 heat inserts instead of M4 heat inserts)
- Corrected the hight of the swingarms
- Updated STL Files accordingly
- Updated STP File accordingly

---
## [1.0.7] — 2026-06-04

### Changed
- Added donate button and badges

## [1.0.6] — 2026-05-30

### Changed
- enlarge counterbores in turning head by 0.5 mm

## [1.0.5] — 2026-05-30

### Changed
- Modified Final.JPG and Tools.JPG, so that git recognized a change and I am now able to push the changes

## [1.0.4] — 2026-05-30

### Changed
- Renamed Tools.jpg to Tools.JPG, so that it will no be displayed in the readme.md 

## [1.0.3] — 2026-05-30

### Changed
- Removed vlc-help.txt file which was accidentally added
- Renamed Final.jpg to Final.JPG, so that it will no be displayed in the readme.md 

## [1.0.2] — 2026-05-30

### Changed
- Added animated GIF previews for the demo videos in the main README.
- Standardized the project naming in the README files to ST3215 Servo Gripper.

## [1.0.1] — 2026-05-30

### Changed

## [1.0.0] — 2026-05-30

### Added
- initial version

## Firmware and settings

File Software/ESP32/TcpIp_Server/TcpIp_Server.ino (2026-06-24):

// WIFI_AP settings.
const char* AP_SSID = "ESP32_DEV";
const char* AP_PWD  = "12345678";

// WIFI_STA settings.
const char* STA_SSID = "OnePlus 8";
const char* STA_PWD  = "40963840";

// the MAC address of the device you want to ctrl.
uint8_t broadcastAddress[] = {0x88, 0x57, 0x21, 0x74, 0xB4, 0x84};
// uint8_t broadcastAddress[] = {0xFF, 0xFF, 0xFF, 0xFF, 0xFF, 0xFF};


typedef struct struct_message {
  int ID_send;
  int POS_send;
  int Spd_send;
} struct_message;

// Create a struct_message called myData
struct_message myData;

// set the default role here.
// 0 as normal mode.
// 1 as leader, ctrl other device via ESP-NOW.
// 2 as follower, can be controled via ESP-NOW.
#define DEFAULT_ROLE 0

// set the default wifi mode here.
// 1 as [AP] mode, it will not connect other wifi.
// 2 as [STA] mode, it will connect to know wifi.
#define DEFAULT_WIFI_MODE 1

// the uart used to control servos.
// GPIO 18 - S_RXD, GPIO 19 - S_TXD, as default.
#define S_RXD 18
#define S_TXD 19

// the IIC used to control OLED screen.
// GPIO 21 - S_SDA, GPIO 22 - S_SCL, as default.
#define S_SCL 22
#define S_SDA 21

// the GPIO used to control RGB LEDs.
// GPIO 23, as default.
#define RGB_LED   23
#define NUMPIXELS 10

// set the max ID.
int MAX_ID = 20;

// modeSelected.
// set the SERIAL_FORWARDING as true to control the servos with USB.
bool SERIAL_FORWARDING = false;

// OLED Screen Dispaly.
// Row1: MAC address.
// Row2: VCC --- IP address.
// Row3: MODE:Leader/Follower  [AP]/[STA][RSSI]
//       DEFAULT_ROLE: 1-Leader(L)/ 2-Follower(F).
//       DEFAULT_WIFI_MODE: 1-[AP]/ 2-[STA][RSSI] / 3-[TRY:SSID].
//       (no matter what wifi mode you select, you can always ctrl it via ESP-NOW.)
// Row4: the position of servo 1, 2 and 3.
String MAC_ADDRESS;
IPAddress IP_ADDRESS;
byte   SERVO_NUMBER;
byte   DEV_ROLE;
byte   WIFI_MODE;
int    WIFI_RSSI;

// set the interval of the threading.
#define threadingInterval 600
#define clientInterval    10

#if CONFIG_FREERTOS_UNICORE
#define ARDUINO_RUNNING_CORE 0
#else
#define ARDUINO_RUNNING_CORE 1
#endif

#include "RGB_CTRL.h"
#include "STSCTRL.h"
#include "CONNECT.h"
#include "BOARD_DEV.h"


void setup() {
  Serial.begin(115200);
  while(!Serial) {}

  espNowInit();

  getMAC();
  
  boardDevInit();

  RGBcolor(0, 64, 255);

  servoInit();

  wifiInit();

  webServerSetup();

  RGBoff();

  delay(1000);
  pingAll(true);

  threadInit();
}


void loop() {
  delay(300000);

  // st.WritePosEx(1, 25, 600, 0);
  // st.WritePosEx(2, 25, 600, 0);
  // st.WritePosEx(3, 25, 600, 0);
  // delay(2000);

  // st.WritePosEx(1, 1000, 600, 0);
  // st.WritePosEx(2, 1000, 600, 0);
  // st.WritePosEx(3, 1000, 600, 0);
  // delay(2000);
}


// > > > > > > > > > DOC < < < < < < < < <
// === Develop Board Ctrl ===
// get the MAC address and save it in MAC_ADDRESS;
// getMAC();

// Init GPIO.
// pinMode(PIN_NUM, OUTPUT);
// pinMode(PIN_NUM, INPUT_PULLUP);

// set the level of GPIO.
// digitalWrite(PIN_NUM, LOW);
// digitalWrite(PIN_NUM, HIGH);

// PWM output(GPIO).
// int freq = 50;
// resolution = 12;
// ledcSetup(PWM_NUM, frep, resolution);
// ledcAttachPin(PIN_NUM, PWM_NUM);
// ledcWrite(PWM_NUM, PWM);


// === Servo Ctrl ===
// GPIO 18 as RX, GPIO 19 as TX, init the serial and the servos.
// servoInit();

// set the position as middle pos.
// setMiddle(servoID);
// st.WritePosEx(ID, position, speed, acc);



// === Devices Ctrl ===
// ctrl the RGB.
// 0 < (R, G, B) <= 255
// setSingleLED(LED_ID, matrix.Color(R, G, B));

// init the OLED screen, RGB_LED.
// boardDevInit();

// dispaly the newest information on the screen.
// screenUpdate();

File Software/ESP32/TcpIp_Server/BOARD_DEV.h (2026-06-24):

#include <Wire.h>
TaskHandle_t ScreenUpdateHandle;
TaskHandle_t ClientCmdHandle;

// SSD1306: 0x3C
#include <Adafruit_SSD1306.h>
#define SCREEN_WIDTH 128 // OLED display width, in pixels
#define SCREEN_HEIGHT 32 // OLED display height, in pixels, 32 as default.
#define OLED_RESET     -1 // Reset pin # (or -1 if sharing Arduino reset pin)
#define SCREEN_ADDRESS 0x3C ///< See datasheet for Address; 0x3D for 128x64, 0x3C for 128x32
Adafruit_SSD1306 display(SCREEN_WIDTH, SCREEN_HEIGHT, &Wire, OLED_RESET);


void InitScreen(){
  if(!display.begin(SSD1306_SWITCHCAPVCC, SCREEN_ADDRESS)) {
    Serial.println(F("SSD1306 allocation failed"));
  }
  display.clearDisplay();
  display.display();
}


void screenUpdate(){
  display.clearDisplay();
  display.setTextSize(1);
  display.setTextColor(SSD1306_WHITE);
  display.setCursor(0,0);
  // Row1.
  display.print(F("MAC:"));display.println(MAC_ADDRESS);
  // Row2.
  display.print(F("V:"));display.print(float(voltageRead[listID[activeNumInList]])/10);display.print(F(" "));display.println(IP_ADDRESS);
  // Row3.
  display.print(F("MODE:"));

  if(DEV_ROLE == 1){display.print(F("L"));}
  else if(DEV_ROLE == 2){display.print(F("F"));}
  else if(DEV_ROLE == 0){display.print(F("N"));}

  if(WIFI_MODE == 1){display.print(F(" AP "));display.println(AP_SSID);}
  else if(WIFI_MODE == 2){display.print(F(" STA "));display.print(F("RSSI"));display.println(WIFI_RSSI);}
  else if(WIFI_MODE == 3){display.print(F(" TRY:"));display.print(STA_SSID);display.println(F(""));}

  // Row4.
  if(searchNum){
    display.print(F("N:"));display.print(searchNum);display.print(F(" ID:"));display.print(listID[activeNumInList]);
    display.print(F("-"));display.print(modeRead[listID[activeNumInList]]);
    display.print(F(" POS:"));display.println(posRead[listID[activeNumInList]]);
  }
  else{
    display.println(F("No servo detected."));
  }
  display.display();
}


void pingAll(bool searchCommand){
  if(searchCommand){
    RGBcolor(0, 255, 64);
    searchNum = 0;
    searchedStatus = true;
    searchFinished = false;
    int PingStatus;
    for(int i = 0; i <= MAX_ID; i++){
      PingStatus = st.Ping(i);

      display.clearDisplay();
      display.setTextSize(1);
      display.setTextColor(SSD1306_WHITE);
      display.setCursor(0,0);
      display.println(F("Searching Servos..."));
      display.print(F("MAX_ID "));display.print(MAX_ID);
      display.print(F("-Ping:"));display.println(i);
      display.print(F("Detected:"));

      for(int i = 0; i < searchNum; i++){
        display.print(listID[i]);display.print(F(" "));
      }
      display.display();

      if(PingStatus!=-1){
        listID[searchNum] = i;
        searchNum++;
      }
      // delay(1);
    }
    for(int i = 0; i< searchNum; i++){
      Serial.print(listID[i]);Serial.print(" ");
      Serial.println("");
    }
    searchedStatus = false;
    searchFinished = true;
    searchCmd      = false;
    RGBoff();
  }
}


void boardDevInit(){
    Wire.begin(S_SDA, S_SCL);
    InitScreen();
    InitRGB();
}


void espNowSendData(){
  // Set values to send
  myData.ID_send = listID[activeNumInList];
  myData.POS_send = posRead[listID[activeNumInList]];
  myData.Spd_send = speedRead[listID[activeNumInList]];
  
  // Send message via ESP-NOW
  esp_err_t result = esp_now_send(broadcastAddress, (uint8_t *) &myData, sizeof(myData));
   
  if (result == ESP_OK) {
    Serial.println("Sent with success");
  }
  else {
    Serial.println("Error sending the data");
  }
  delay(200);
}


void InfoUpdateThreading(void *pvParameter){
  while(1){
    if(!SERIAL_FORWARDING && !RAINBOW_STATUS){
      getFeedBack(listID[activeNumInList]);
      getWifiStatus();
      screenUpdate();
      delay(threadingInterval);
      pingAll(searchCmd);
    }
    else if(SERIAL_FORWARDING){
      display.clearDisplay();
      display.setTextSize(1);
      display.setTextColor(SSD1306_WHITE);
      display.setCursor(0,0);
      display.println(F(" - - - - - - - -"));
      display.println(F("SERIAL_FORWARDING"));
      display.println(F(" - - - - - - - -"));
      display.display();
      delay(1000);
    }
    else if(RAINBOW_STATUS){
      display.clearDisplay();
      display.setTextSize(3);
      display.setTextColor(SSD1306_WHITE);
      display.setCursor(0,0);
      display.println(F("RAINBOW"));
      display.display();
      rainbow(30);
    }
  }
}
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

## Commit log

2026-05-29 V1.0.0
    - Initial Version
    [Baseplate.stl, Finger_1.stl, Finger_2.stl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]
2026-05-29 V1.0.1
    - Fixed an issue that the image Final.jpg was not displyed because of upper / lower case
2026-05-30 1.0.2
    - Added animated GIF previews for the demo videos in the main README.
    - Standardized the project naming in the README files to ST3215 Servo Gripper.
2026-05-31 1.0.6
    - enlarge counterbores in turning head by 0.5 mm
    [Gripper.step, Turnhead.stl]
2026-06-04 1.0.7
    - Added donate button and badges
2026-06-05 1.0.8
    - Corrected some scew lengths in BOM list ( bill of material )
    - Corrected the depth for the hex holes in the base plate, so that a M2x20 screw can be screwed in - before the screw was to short
    - Corrected the hole diameter of the 4 flange holes ( it is now for M3 heat inserts instead of M4 heat inserts)
    - Corrected the hight of the swingarms
    - Updated STL Files accordingly
    - Updated STP File accordingly
    [Baseplate.stl, Gripper.step, Motorhousing.stl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]
2026-06-24 V1.0.9
    Added:
    - Serial Board.step STL/DIN Rail Holder Serial Board.stl , Assembly/DIN Rail Holder.jpeg
    - Added dedicated ESP32 documentation in Software/ESP32/Readme.md.
    Changed:
    - Updated ReadMe.md (DE/EN) to include DIN rail holder image preview and links for the new STEP/STL files.
    - Updated Software/Readme.md (DE/EN) with a direct reference to the ESP32 firmware documentation.
    - Expanded Software/ESP32/Readme.md with: fixed, tested Arduino package/library version set
    [Baseplate.stl, Baseplate_Multi.stl, DIN Rail Holder Serial Board.step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]
2026-06-28 V1.0.10
    ### Added
    - Added SO-ARM-101 compatible motorhousing STL file `STL/Motorhousing SO-ARM-101.stl`
    - Added `STL/Motorhousing Cover with Handle.stl`
    - Added cam holder STL file: `STL/Cam Holder.stl`
    - Added DIN rail ESP32 adapter STL file: `STL/DIN Rail Holder ESP32 Adapter.stl`
    - Added SO-ARM-101 assembly preview image: `Assembly/SO-Arm-101.jpeg`
    [Cam Holder.stl, DIN Rail Holder ESP32 Adapter.stl, Motorhousing Cover with Handle.stl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]
2026-08-07 V1.0.11
    - Added a Python TCP/IP bridge example that enables remote control of a USB-connected servo board over TCP/IP.
    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
    [Cam Holder.stl]
